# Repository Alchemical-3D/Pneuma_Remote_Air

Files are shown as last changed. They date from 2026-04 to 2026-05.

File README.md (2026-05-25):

<div align="center">

# 🌬️ Pneuma Part Cooling







> [!NOTE]
> **Dual-Pump Architecture**
> Pneuma has recently been upgraded to a dual-pump system (removing the previous direct-acting solenoid valve). This allows for independent, granular control over ambient room air and warm internal chamber air.

A professional, high-performance pneumatic part cooling system designed for the Alchemical-3D ecosystem. Pneuma utilizes vacuum pump(s) and tubes to deliver highly precise, compressed air cooling to toolheads such as the Alembic.

<p align="center">
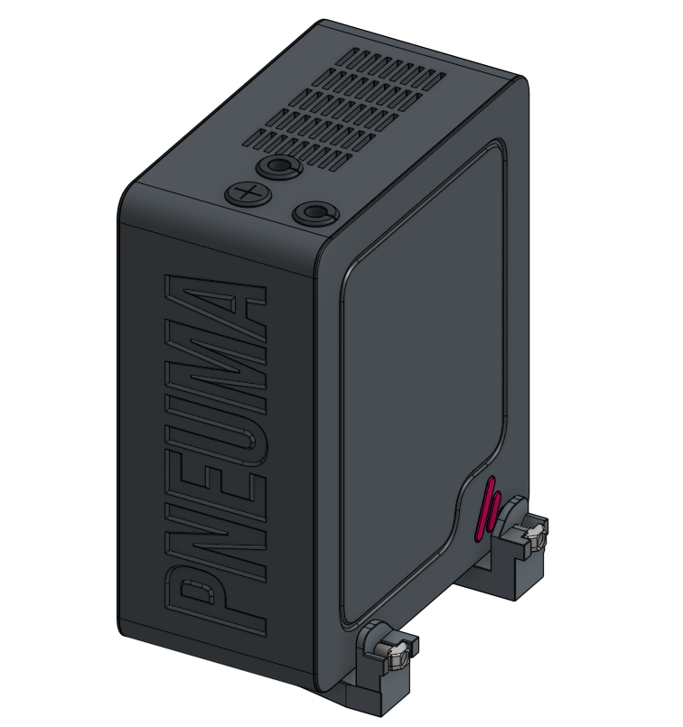
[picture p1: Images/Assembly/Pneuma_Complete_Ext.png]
Pneuma Image 1
  
  &nbsp;
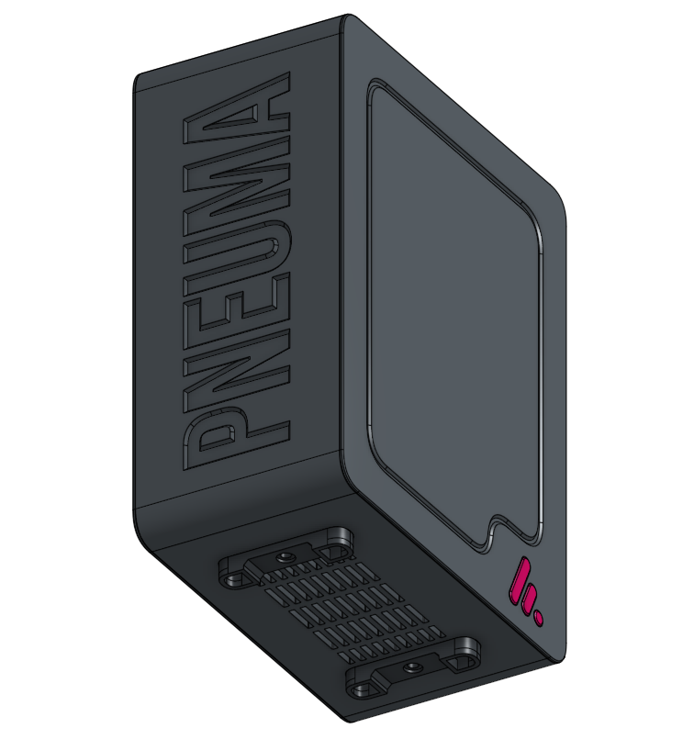
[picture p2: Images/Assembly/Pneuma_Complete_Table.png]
Pneuma Image 2
  
</p>

</div>

<br>

## 📚 Documentation Index

Everything you need to set up and configure the Pneuma system:

| Category | Description |
| :--- | :--- |
| 📋 **[Bill of Materials (BOM)](BOM.md)** | The comprehensive checklist of printed parts, pumps, tubing, and hardware needed. |
| 🛠️ **[Assembly Guide](Assembly_Guide.md)** | A step-by-step mastercloth for putting the Pneuma system together. |
| ⚙️ **[Print Settings](Print_Settings.md)** | Essential slicer configurations, material recommendations, and orientation rules for the enclosures. |

<br>

---
> [!IMPORTANT]
> **Alpha Release**
> This project is currently in the **Alpha phase** of development. Please expect ongoing changes, updates, and improvements to the designs and documentation as the system evolves.

> [!TIP]
> **Looking for a Compatible Toolhead?**<br>
> *If you're interested in this project, check out the **[Alembic Toolhead](https://github.com/Alchemical-3D/Alembic_Toolhead)** project! It is a lightweight, high-performance toolhead designed for the Alchemical-3D ecosystem to utilize Pneuma's remote compressed air architecture.*

## 🌪️ System Capabilities & Benefits

Pneuma provides an alternative approach to part cooling by relocating airflow generation away from the toolhead. By utilizing remote vacuum pumps and pneumatic tubing, Pneuma offers several distinct advantages:

- **Targeted Cooling:** By replacing wide-area blowers with focused, high-velocity air at the nozzle exit, Pneuma and a compatible toolhead will help improve overhangs and fine details.
- **Air Source Control:** When paired with Klipper, users can dynamically select their air source—switching between ambient room air or warm internal chamber air. Pneuma utilizes dual dedicated pumps for this, providing extensive and reliable options for makers to best suit their needs.
- **Smart Macro Integration:** Pneuma uses custom Klipper macros to seamlessly intercept standard part cooling commands (`M106`/`M107`). The system can be commanded manually through the Klipper interface, or entirely through your slicer's standard G-code by embedding a simple mode toggle in your filament profiles.
- **Lightweight Toolheads:** Due to removing the typical 4010 or 5015 blowers, toolheads like the [Alembic](https://github.com/Alchemical-3D/Alembic_Toolhead) shed mass, directly benefiting mechanical properties during operation such as acceleration and jerk.
- **Noise Mitigation:** Pneuma utilizes carefully selected, enclosed pumps (similar to premium aquarium & medical equipment) designed to run quieter than typical "Berd Air" or unshielded pressurized air setups, and when configured properly, can be quieter than the fans themselves.
- **Enhanced Visibility:** Removing bulky fans provides a clearer, less obstructed view of the extrusion process, aiding in visual or camera-based print monitoring.
- **Adaptable Performance:** The modular design allows users to swap pump capacities to better suit their specific cooling needs and materials.

---

## ✨ Key Specifications & Features

- **Cooling Delivery:** High-speed compressed air routed via dedicated pneumatic tubing.
- **Pump Integration:** Low noise, reliable vacuum pump operation.
- **Ecosystem Synergy:** Fully compatible with the Alchemical-3D [Alembic](https://github.com/Alchemical-3D/Alembic_Toolhead) and the A3DP gantry kit, also able to support other berd-air toolheads.
- **Professional Package:** Engineered for repeatability, simple service, and long-term reliability.

---

## 🎛️ Firmware & Control

Pneuma relies on a custom Klipper macro to intelligently route standard part cooling commands to the correct pump. This allows you to retain all native slicer cooling behaviors while utilizing dual air sources.

### Klipper Configuration
The required configuration file can be found here: **[Pneuma_Control.cfg](Firmware/Pneuma_Control.cfg)**

1. **Install:** Place the `Pneuma_Control.cfg` file in your Klipper configuration directory and `[include]` it in your `printer.cfg`.
2. **Assign Pins:** Open the file and assign the correct MCU pins for your Cool Pump and Warm Pump. 
3. **Remove Old Fans:** Ensure you comment out or delete your default `[fan]` component in `printer.cfg` to prevent conflicts.

### How to Use
The system intercepts standard `M106` (fan on) and `M107` (fan off) commands. You can dynamically switch which pump receives these commands using the `SET_PNEUMA_MODE` macro.

**Available Modes:**
- `MODE=COOL` : Routes all cooling commands to the dedicated external cool air pump. Ideal for PLA, PETG, and materials needing maximum thermal extraction.
- `MODE=WARM` : Routes all cooling commands to the internal chamber pump. Ideal for ABS, ASA, and materials sensitive to drafts or warping.
- `MODE=DUAL` : Spins up *both* pumps simultaneously when cooling is requested. Reserved for extreme airflow needs.
- `MODE=OFF` : Completely disables part cooling routing to both pumps, ignoring slicer commands until a new mode is set.

**Implementation Examples:**
- **Via Slicer:** Add `SET_PNEUMA_MODE MODE=WARM` to your filament start G-code for ABS/ASA, or `MODE=COOL` for PLA.
- **Via Console:** Type `SET_PNEUMA_MODE MODE=DUAL` in the Klipper terminal for a quick override.
- **Automatic Routing:** When the slicer requests cooling (e.g., `M106 S255`), Klipper will automatically send the PWM signal only to the active pump(s). If you change modes mid-print, the current fan speed is immediately routed to the new pump!

***

## ⚖️ License

This project is licensed under the **Creative Commons Attribution-NonCommercial-ShareAlike 4.0 International License**. See the [LICENSE.md](LICENSE.md) file for details.

***

**[Join the Discord!](https://discord.gg/aE49DW2xXe)**

> ☕ **Did you find this guide helpful?** 
> 
> My projects are open-source and free for the community. If you've enjoyed my designs and want to support my work, consider [leaving me a tip on Ko-fi](https://ko-fi.com/alchemical3d)! 
>
>

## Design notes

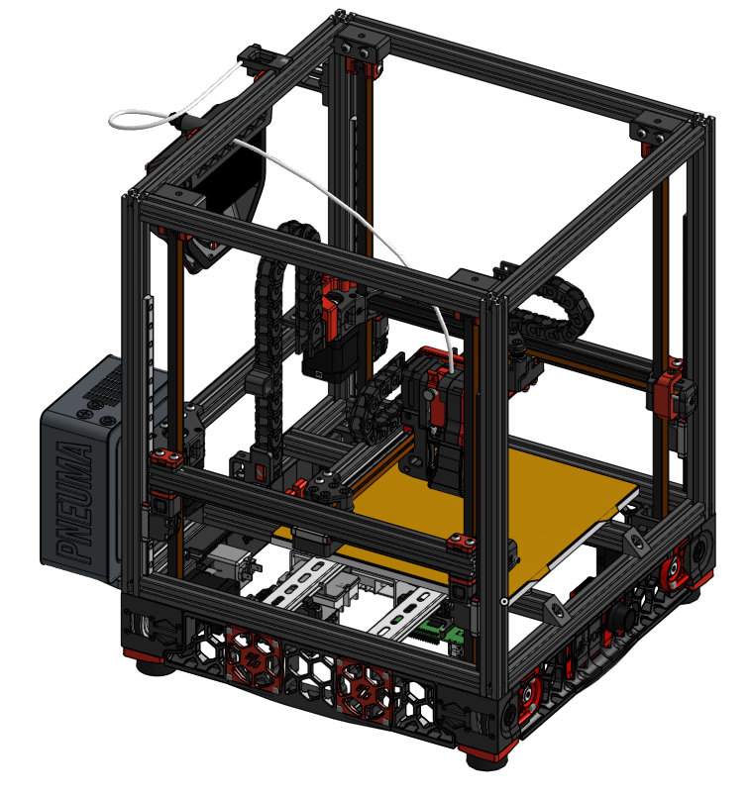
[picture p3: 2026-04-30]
Images/Pneuma_v2-4_side.png

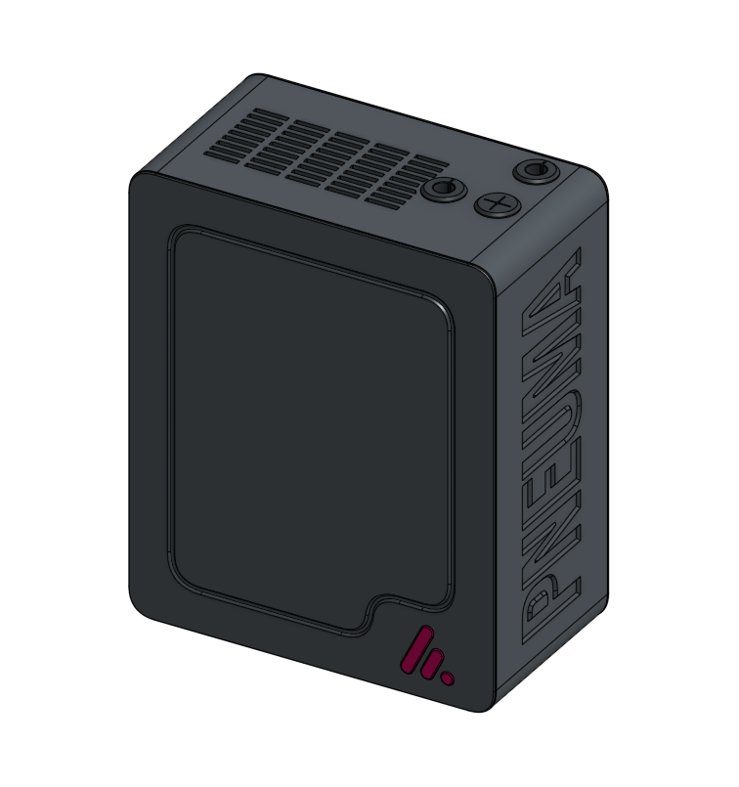
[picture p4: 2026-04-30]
Images/Pneuma.png

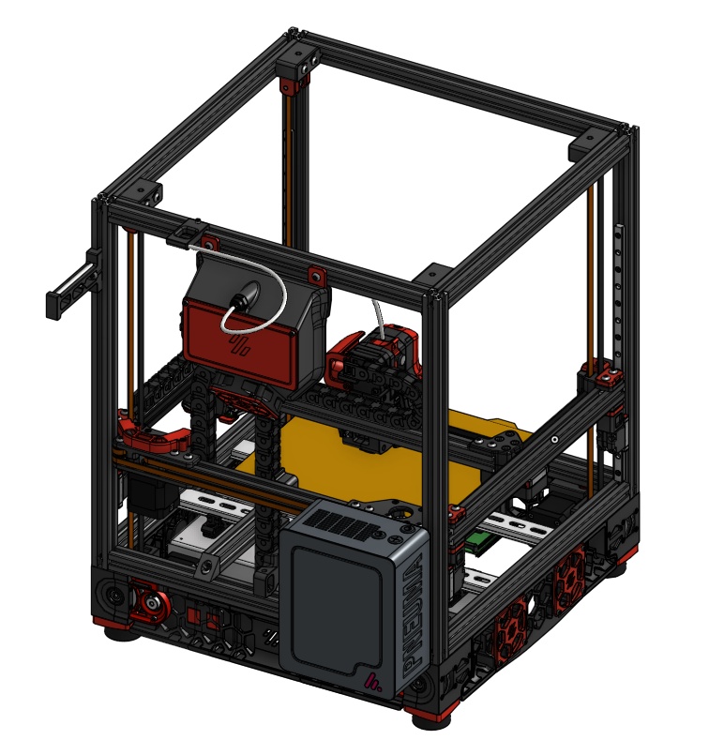
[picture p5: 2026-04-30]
Images/Pneuma_v2-4_back.png

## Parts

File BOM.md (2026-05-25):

# 📋 Bill of Materials (BOM)

This list contains all the 3D-printed and physical hardware required to assemble the Pneuma Part Cooling system.

> [!NOTE]
> **Affiliate Links**
> Alchemical-3D has affiliate status with most of the links below. Purchases using these links helps fund the project at no cost to you!  Some of these links even provide a discount off the retail price.

> [!CAUTION]
> **Valve Selection**
> If you choose to configure your Pneuma with a solenoid valve, it is critical that it is **direct acting** or **vacuum acting**. Pressure-acting valves will not function correctly in this vacuum-based system. Some double solenoid valves are able to fully function as long as the core is shared between solenoids.   Please ask on our [Discord](https://discord.gg/r97kK5B7B7) if you are unsure about a specific valve. 

> [!NOTE]
> **Pump Specifications**
> When selecting a vacuum pump, ensure it meets the following minimum specifications for effective part cooling:
> *   **Flow Rate:** Greater than 10L/min (for part cooling only)
> *   **Pressure:** 70 kPa or better
> *   **Vacuum:** -40 kPa or better
> *   **Voltage:** Ensure the pump's voltage matches your intended power supply configuration. 

## 1. Printed Parts

Print these out using the guidelines specified in the [Print Settings](Print_Settings.md) page.

| Part File Name | Qty | Description / Notes | Material | Color |
| --- | :---: | --- | --- | --- |
| `Main_Body.stl` | 1 | Main Body | ABS/ASA | Primary |
| `Rear_Cover.stl` | 1 | Rear Cover | ABS/ASA | Primary |
| `Front_Cover.stl` | 1 | Front Cover | ABS/ASA | Primary |
| `Logo_Detail.stl` | 2 | Logo Detail | ABS/ASA | Accent |
| `Pump_Mount(s).stl` | 2 | Pump Mount | ABS/ASA | Primary |
| `Tube_Grommet.stl` | 3 | Tube Grommet | TPU | Any |
| `Plug_Grommet.stl` | 3 | Plug Grommet | TPU | Any |
| `Table_Mount.stl` | 2 | Optional Table Mount | TPU | Any |
| `Extrusion_Mount_A.stl` | 1 | Optional Extrusion Mount A | ABS/ASA | Primary |
| `Extrusion_Mount_B.stl` | 1 | Optional Extrusion Mount B | ABS/ASA | Primary |
| `Tube_Fitting.stl` | 3 | Fitting, Hardware Dependent | TPU | Any |

> [!NOTE]
> **Additional Printed Parts**
> Additional printed parts may be required for specific use cases, such as tube adaptors for vacuum pumps that have different outlet sizes than the standard pneumatic tubing. A folder will eventually be added to the repository containing a selection of these adaptors for the most common sizes (e.g. 6mm, 8mm, etc.).

## 2. Fasteners and Hardware

| Item | Qty (Est.) | Description |
| --- | :---: | --- |
| **[M3x5x4 Heatsets](https://kb-3d.com/store/inserts-fasteners-adhesives/278-brass-heat-set-threaded-insert-for-plastic-m3x5x4mm.html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)** | 5 | Used in the Rear Cover for the Pump Mount |
| **[M3x10 SHCS](https://amzn.to/3P57ILQ)** | 2 | Foot Mounting (Extrusion or Table) |
| **[M3x8 SHCS](https://amzn.to/3P57ILQ)** | 2 | Pump Mounting |
| **[Pneumatic Tubing](https://amzn.to/3P3YzDd)** | 1 | Other diameters will require changes to BOM |
| **[Pneumatic Fitting (1/8 NPT, 6mm OD)](https://amzn.to/3P3YzDd)** | 1 | Valve Chamber Inlet  |
| **[Pneumatic Fitting Right Angle(1/8 NPT, 6mm OD)](https://amzn.to/3P3YzDd)** | 1 | Pump Intake: Helps with tubing bend radius |
| **[M5x12 BHSC](https://amzn.to/42p7gvb)** | 2 | Extrusion Mounting |
| **[M5 Roll in T Nut](https://kb-3d.com/store/extrusion-framing/252-t-nut-drop-inroll-in-20-series-6mm-slot-width-m5-threads-1657989339400.html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)** | 2 | Extrusion Mounting |

## 3. Electronics

| Item | Qty | Description |
| --- | :---: | --- |
| **[Vacuum Pump(s)](https://amzn.to/4ubXFnG)** | 1 or 2 | This link is for the version of the pump that is currently installed in the alpha.  |
| **[Solenoid Valve 3-Way Vacuum Direct Acting](https://amzn.to/3Qx0UXL)** | 1 | Optional, required for air temperature control. |
| **[20AWG High-Temp FEP Wire](https://kb-3d.com/store/wiring-connectors/5530-9177-3do-high-temperature-motion-rated-tc-fep-wire-multiple-sizes-colors.html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)** | As Needed | 20AWG, depends on pump current requirements, link is excellent option. |
| **[5-PIN Single Row Molex Micro-Fit 3.0](https://amzn.to/3ODzcbj)** | 1 Each | Male/Female Connectors, pins not included |

> [!IMPORTANT]
> **Part Flexibility & Modifications**
> There is flexibility in the hardware and components you can use for this build. However, please note that veering from the listed parts may require you to modify the 3D models to accommodate your specific hardware. To make this process easier, **STEP files are provided** in the GitHub repository for all printed parts. If you need help with modifications or have specific hardware requests, feel free to join our [Discord](https://discord.gg/r97kK5B7B7) and reach out!

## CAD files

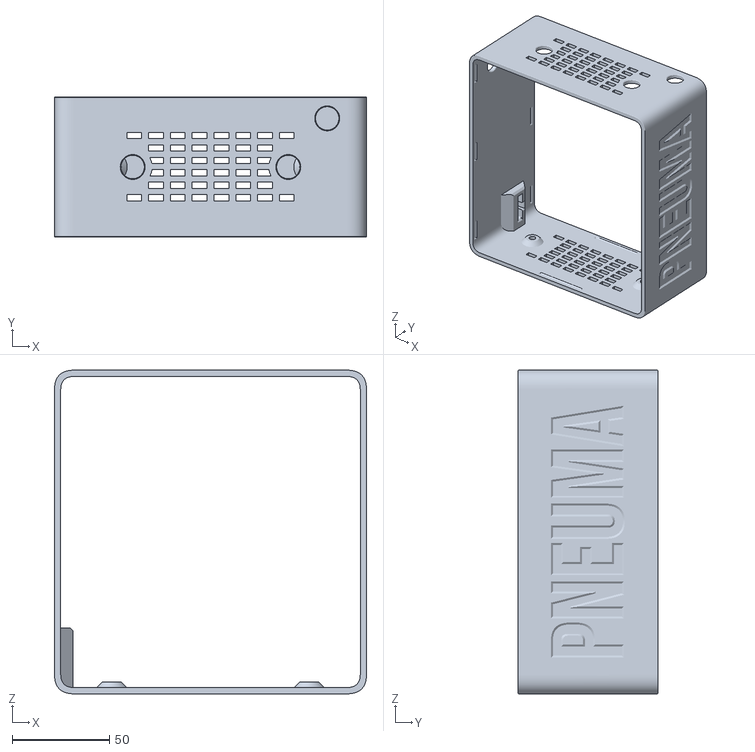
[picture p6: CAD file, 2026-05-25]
STL_Files/Pneuma_201 parts - Main_Body.stl
160.4 x 72.0 x 166.4

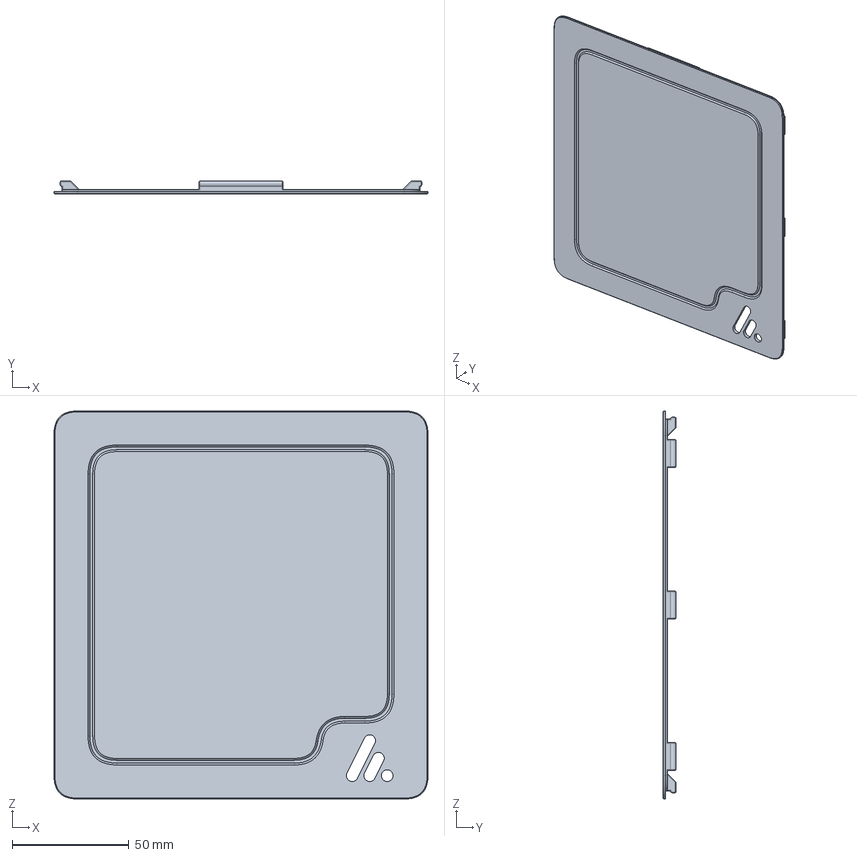
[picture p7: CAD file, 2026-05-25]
STEP_Files/Pneuma_201 parts - Front_Cover(1).step
160.4 x 5.60 x 166.4 mm

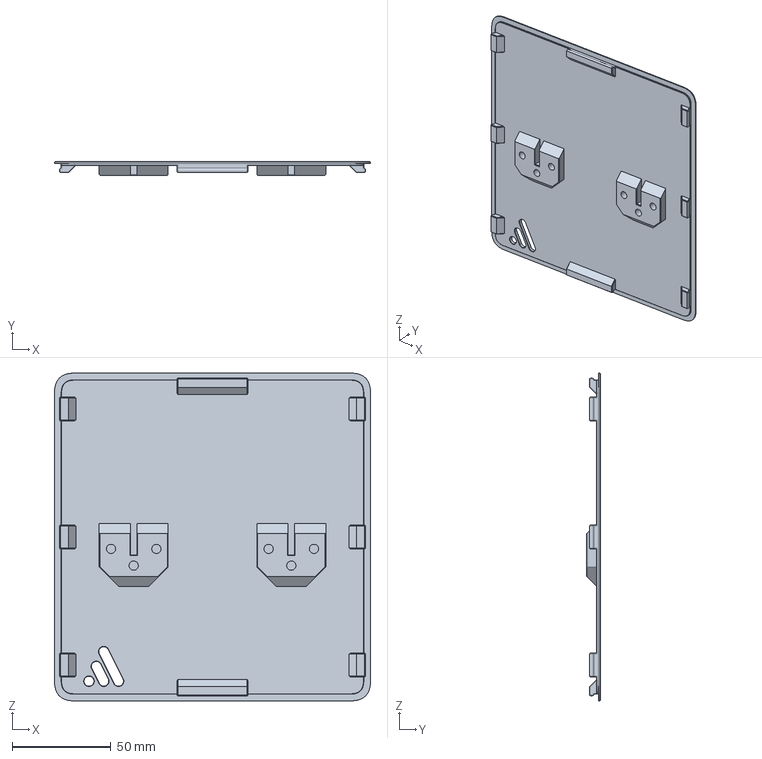
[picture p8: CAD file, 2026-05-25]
STEP_Files/Pneuma_201 parts - Rear_Cover(1).step
160.4 x 7.00 x 166.4 mm

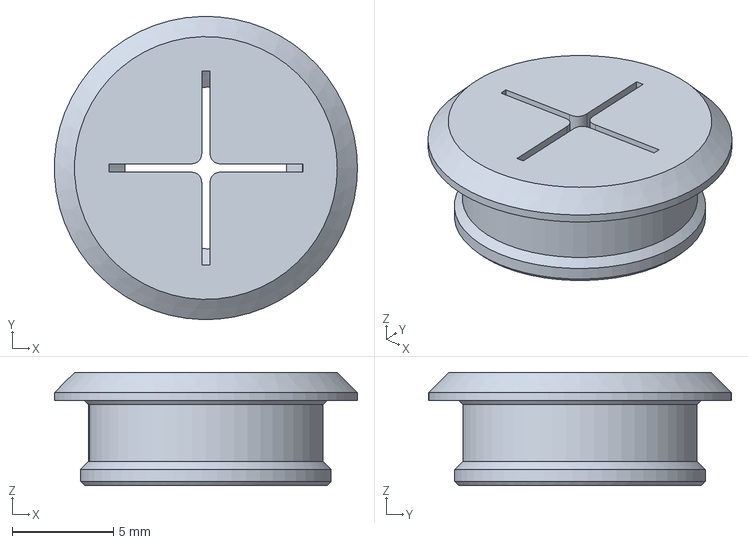
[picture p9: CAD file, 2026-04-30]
STEP_Files/Pneuma_201 - Plug_Grommet_TPU.step
15.0 x 15.0 x 5.60 mm

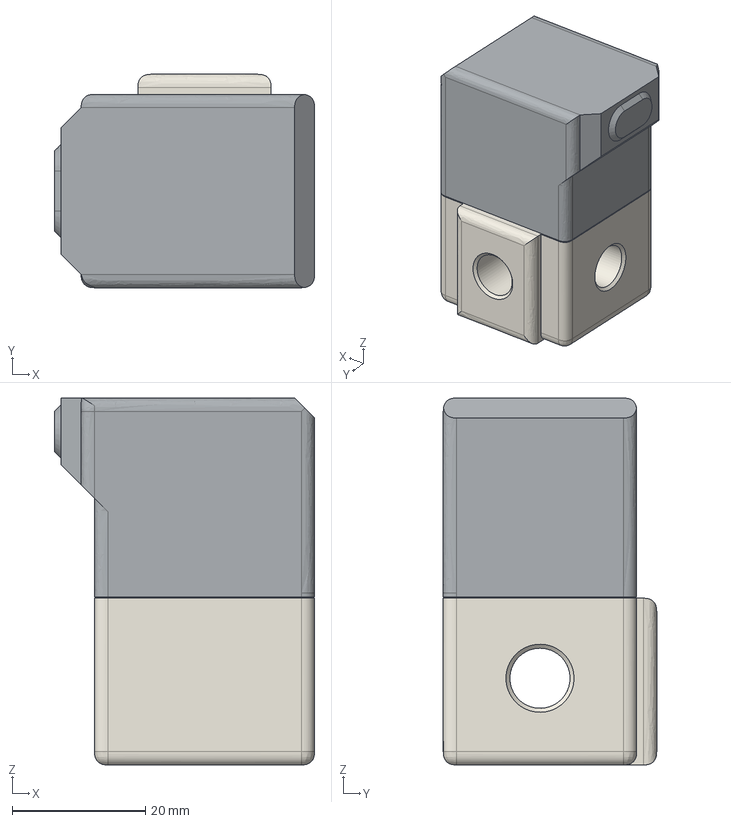
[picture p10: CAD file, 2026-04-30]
STEP_Files/Pneuma_201 - 1-8-NPT Direct_Action_Valve.step
39.0 x 32.0 x 55.0 mm

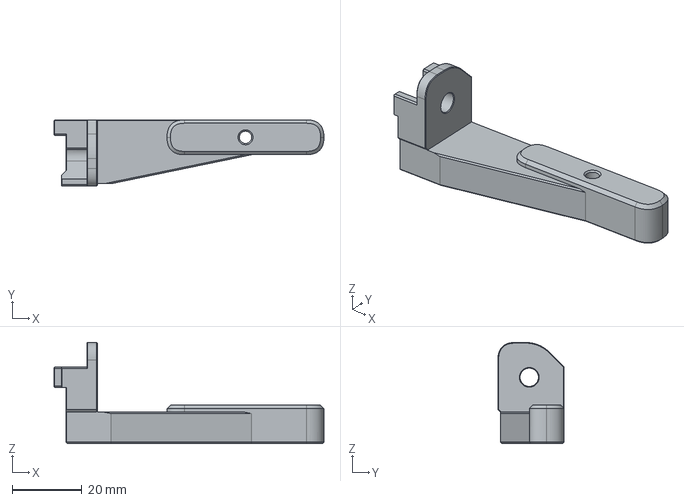
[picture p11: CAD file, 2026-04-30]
STEP_Files/Pneuma_201 - Extrusion_Mount_B.step
77.4 x 19.0 x 29.0 mm

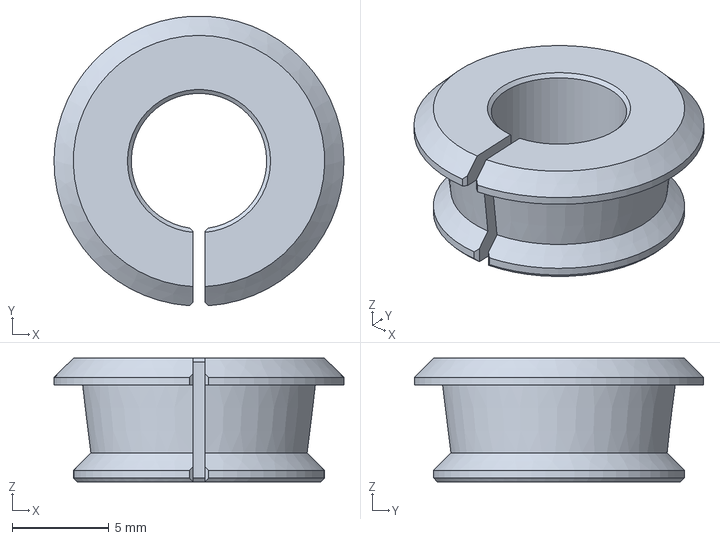
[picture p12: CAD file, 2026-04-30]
STEP_Files/Pneuma_201 - TPU_Grommet.step
15.0 x 15.0 x 6.40 mm

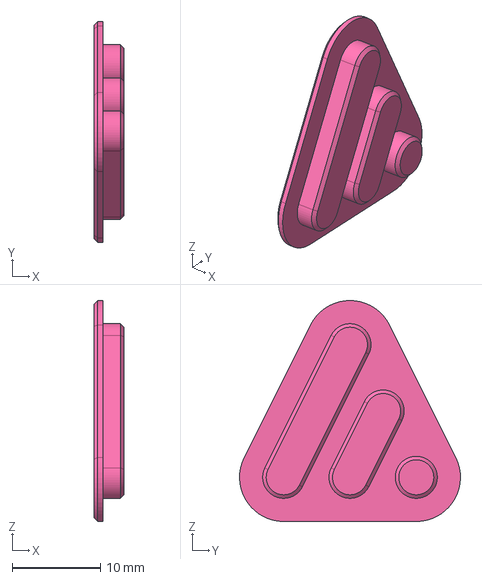
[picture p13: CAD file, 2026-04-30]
STEP_Files/Pneuma_201 - Logo_Detail.step
3.40 x 25.0 x 25.0 mm

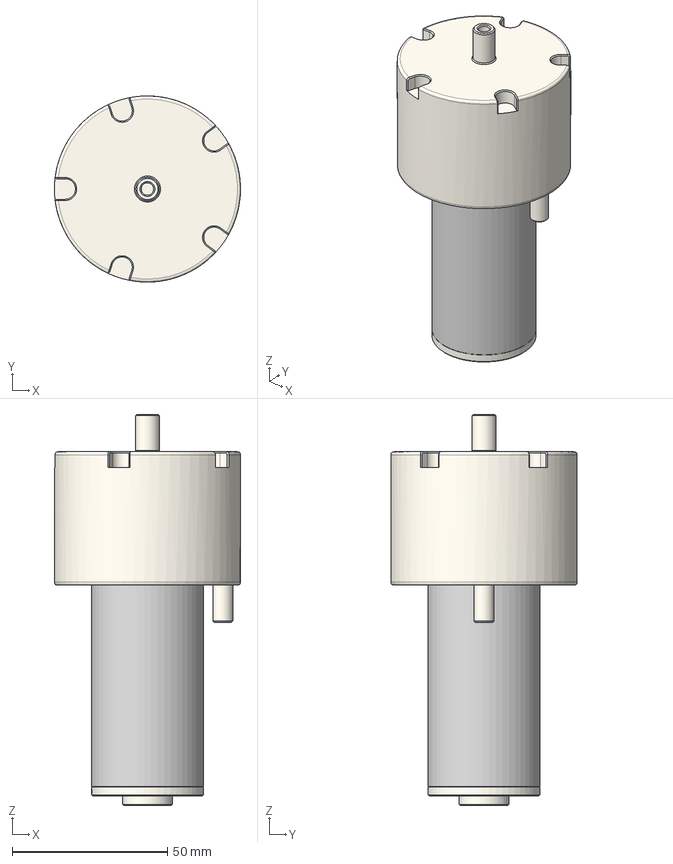
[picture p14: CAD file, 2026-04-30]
STEP_Files/Pneuma_201 - Vacuum_Pump.step
60.0 x 60.0 x 126.0 mm

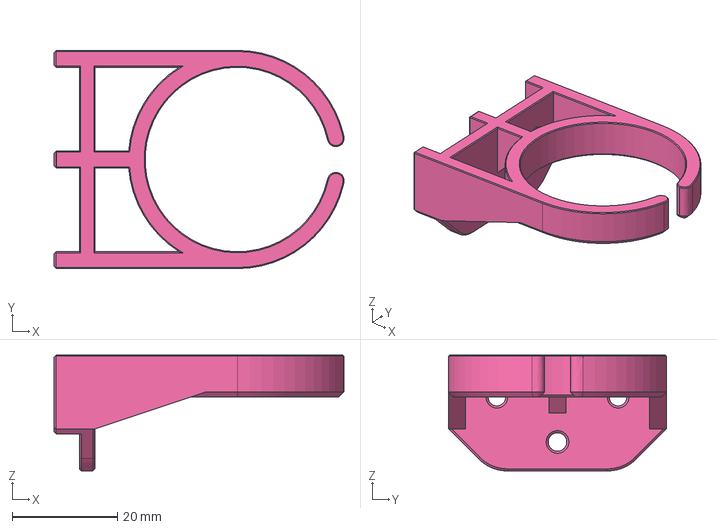
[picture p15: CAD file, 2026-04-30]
STEP_Files/Pneuma_201 - Pump_Mount.step
55.0 x 41.4 x 22.0 mm

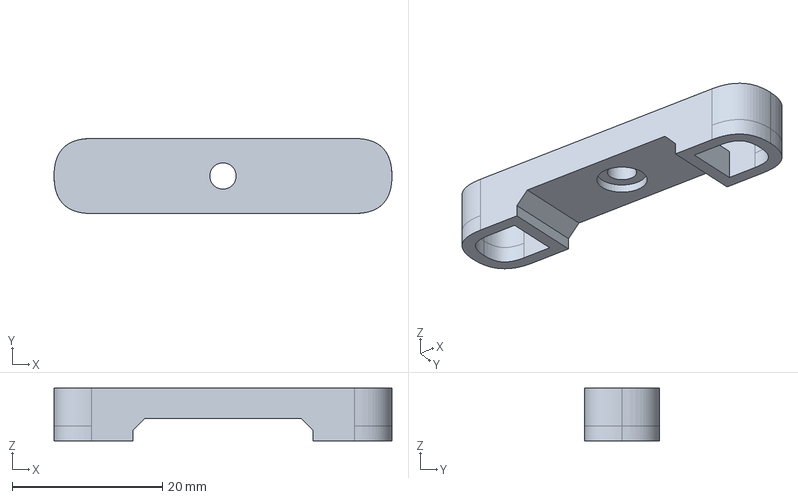
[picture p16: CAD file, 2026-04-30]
STEP_Files/Pneuma_201 - Table_Mount_TPU.step
45.0 x 10.00 x 7.00 mm

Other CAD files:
STEP_Files/Pneuma_201 parts - Main_Body(1).step
STL_Files/Pneuma_201 parts - Front_Cover.stl
STL_Files/Pneuma_201 parts - Rear_Cover.stl
STEP_Files/Pneuma_201 - Extrusion_Mount_A.step
STL_Files/Pneuma_201 - Extrusion_Mount_A.stl
STL_Files/Pneuma_201 - Extrusion_Mount_B.stl
STL_Files/Pneuma_201 - Logo_Detail.stl
STL_Files/Pneuma_201 - Plug_Grommet_TPU.stl
STL_Files/Pneuma_201 - Pump_Mount.stl
STL_Files/Pneuma_201 - TPU_Grommet.stl
STL_Files/Pneuma_201 - Table_Mount_TPU.stl
STL_Files/Pneuma_201 - Vacuum_Pump.stl

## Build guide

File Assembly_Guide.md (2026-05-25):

# 🛠️ Assembly Guide

Welcome to the assembly guide for the Pneuma Part Cooling system.

> [!NOTE]
> **Dual-Pump Architecture**
>
> Pneuma has recently been upgraded to a dual-pump system (removing the previous direct-acting solenoid valve). This allows for independent, granular control over ambient room air and warm internal chamber air.  It also means this assembly guide has changed, but the core principals remain.  This will be updated at a later date.

## Tools Required
- Hex keys
- Flush cutters
- Tube cutter
- Soldering iron (for heat set inserts)

### Note
> [!WARNING]
> **Builder Responsibility**
>
> This is an aftermarket engineering project. You are solely responsible for your own safety and the integrity of your equipment when building and operating this system. By utilizing these files and instructions, you accept all liability.

---

## Step 1: Heat Set Inserts

Begin by installing the M3 heat set inserts into the printed parts. Ensure they are flush with the surface to allow for proper mating of the components.

<div align="center">
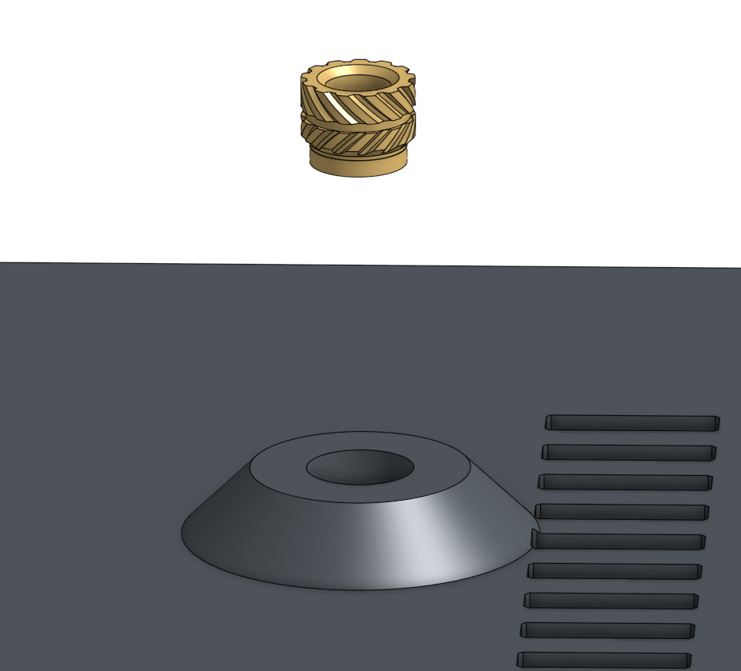
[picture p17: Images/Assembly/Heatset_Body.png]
Heat Set Body
  
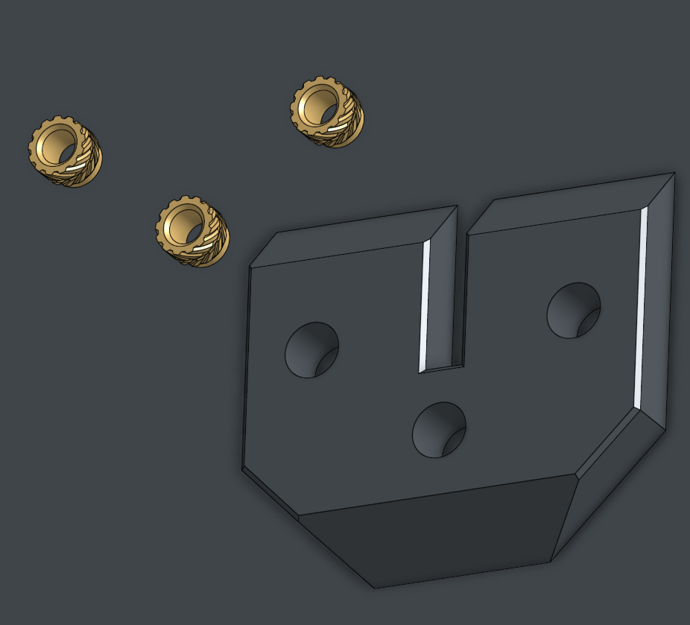
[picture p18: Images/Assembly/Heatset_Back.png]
Heat Set Back
  
</div>
<br>
*Fig. 1: Install M3 inserts into the Main Body and Rear Cover.*

---

## Step 2: Pump Mounting

Attach the vacuum pump to the pump mount using the appropriate screws. Ensure the pump is seated securely.

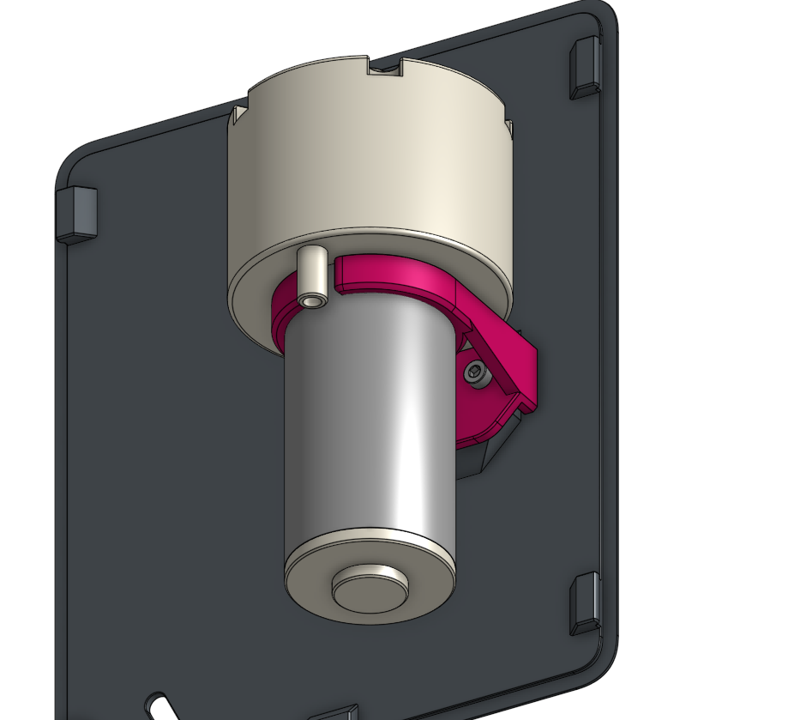
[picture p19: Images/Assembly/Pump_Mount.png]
Pump Mount

<br>
*Fig. 2: Secure the pump to the Pump Mount.*

---

## Step 3: Main Assembly

Bring together the main components. Route the pneumatic tubing and any necessary wiring through the designated channels before closing the covers.

> [!NOTE]
> **Threaded Fittings**
>
> Teflon tape is recommended at a minimum on the pressure side of the line when using threaded fittings.

> [!NOTE]
> **Solenoid Valve Routing**
>
> Typical direct action solenoid valves will have a common outlet, and two switching outlets. The common outlet must go to the pump intake, and for ABS/ASA and higher tier filament machines, it is recommended to have at least one line draw from the chamber to ensure warmer air is an option to avoid warping.

> [!WARNING]
> **Tubing Bend Radius**
>
> Take care when routing the pneumatic tubing. Avoid sharp bends and do not exceed the minimum bend radius of your tubing. Kinked lines will severely restrict airflow and reduce cooling system performance.

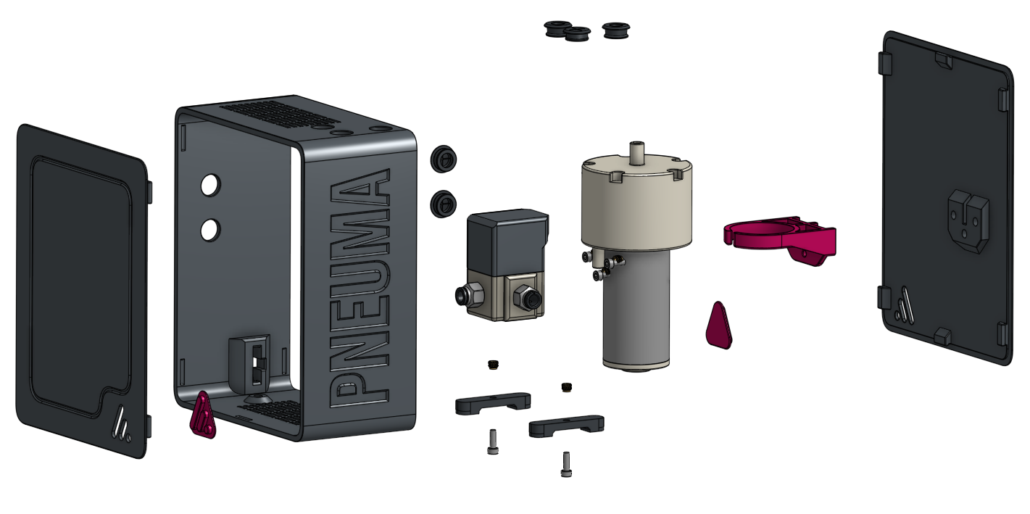
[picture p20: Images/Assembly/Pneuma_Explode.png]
Pneuma Exploded View

<br>
*Fig. 3: Exploded view of the primary Pneuma assembly.*

---

## Step 4: Optional Mounting Solutions

Depending on your setup, you can mount the Pneuma system either to the printer's aluminum extrusion or directly to a table/enclosure surface. 

<div align="center">
  Extrusion Mount
  Table Mount
</div>
<br>
*Fig. 4: Optional Extrusion mount (left) and Table mount (right).*

---

### End of Assembly
The Pneuma Part Cooling system is now assembled and ready for integration!

***

> ☕ **Did you find this guide helpful?** 
> 
> My projects are open-source and free for the community. If you've enjoyed my designs and want to support my work, consider [leaving me a tip on Ko-fi](https://ko-fi.com/alchemical3d)! 
>
>

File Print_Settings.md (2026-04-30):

# ⚙️ Print Settings

*This document is currently a placeholder for the Pneuma Part Cooling system Print Settings.*

## Recommended Materials
- **Pump Enclosure:** ASA / ABS (for thermal resistance) or PETG.
- **Mounts:** ASA / ABS.

## General Slicer Settings
- **Layer Height:** 0.2mm
- **Infill:** 40% Grid or Gyroid
- **Wall Loops:** 4
- **Top/Bottom Layers:** 5

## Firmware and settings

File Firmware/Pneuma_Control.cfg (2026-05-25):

# Pneuma Dual-Pump Control System
# This configuration replaces the standard [fan] with two [fan_generic] definitions
# and overrides the M106/M107 commands to route air based on the selected mode.

# ==============================================================================
# 1. HARDWARE DEFINITIONS
# ==============================================================================
# Define the pins for your two pumps here. 
# IMPORTANT: You must comment out or remove any existing [fan] sections in your main printer.cfg

[fan_generic pump_cool]
pin: PF7 # <--- UPDATE THIS TO YOUR COOL PUMP PIN
min_power: 0.15
max_power: 1.0
#kick_start_time: 0.5
shutdown_speed: 1

[fan_generic pump_warm]
pin: PF9 # <--- UPDATE THIS TO YOUR WARM PUMP PIN
min_power: 0.15
max_power: 1.0
#kick_start_time: 0.5
shutdown_speed: 1

# ==============================================================================
# 2. STATE MANAGEMENT
# ==============================================================================
[gcode_macro PNEUMA_STATE]
description: Stores the current state of the Pneuma system
variable_mode: "COOL" # Default mode on startup (Options: COOL, WARM, DUAL, OFF)
variable_last_speed: 0.0 # Stores the last requested speed to re-apply when switching modes
gcode:
    # This macro just holds variables for the other macros to use.
    # Do not call this directly.

# ==============================================================================
# 3. MODE SWITCHING MACRO
# ==============================================================================
[gcode_macro SET_PNEUMA_MODE]
description: Set the active Pneuma pump mode (COOL, WARM, DUAL, OFF)
gcode:
    {% set new_mode = params.MODE|default("COOL")|string|upper %}
    {% set valid_modes = ["COOL", "WARM", "DUAL", "OFF"] %}
    
    {% if new_mode in valid_modes %}
        SET_GCODE_VARIABLE MACRO=PNEUMA_STATE VARIABLE=mode VALUE='"{new_mode}"'
        {action_respond_info("Pneuma Pump Mode set to: %s" % new_mode)}
        
        # Automatically re-apply the last known fan speed to the new mode
        {% set last_speed = printer["gcode_macro PNEUMA_STATE"].last_speed %}
        {% if last_speed > 0 %}
            # If the fan was on, turning it "on" again will re-route the air
            M106 S{ (last_speed * 255)|int }
        {% else %}
            # Ensure both pumps are off if the last speed was 0
            M107
        {% endif %}
    {% else %}
        {action_respond_info("ERROR: Invalid Pneuma mode '%s'. Must be COOL, WARM, DUAL, or OFF." % new_mode)}
    {% endif %}

# ==============================================================================
# 4. SLICER COMMAND OVERRIDES (M106 / M107)
# ==============================================================================
[gcode_macro M106]
description: Override standard part cooling command to route to active Pneuma pump
gcode:
    # Get requested speed, default to 100% (255) if S parameter is missing
    {% set raw_speed = params.S|default(255)|float %}
    
    # Convert 0-255 range to 0.0-1.0 percentage
    {% set safe_speed = raw_speed / 255.0 %}
    {% if safe_speed > 1.0 %}
        {% set safe_speed = 1.0 %}
    {% elif safe_speed < 0.0 %}
        {% set safe_speed = 0.0 %}
    {% endif %}
    
    # Store this speed so we can recall it if the user switches modes mid-print
    SET_GCODE_VARIABLE MACRO=PNEUMA_STATE VARIABLE=last_speed VALUE={safe_speed}
    
    # Get the current mode
    {% set mode = printer["gcode_macro PNEUMA_STATE"].mode %}
    
    # Apply speeds based on the mode
    {% if mode == "COOL" %}
        SET_FAN_SPEED FAN=pump_cool SPEED={safe_speed}
        SET_FAN_SPEED FAN=pump_warm SPEED=0.0
    {% elif mode == "WARM" %}
        SET_FAN_SPEED FAN=pump_cool SPEED=0.0
        SET_FAN_SPEED FAN=pump_warm SPEED={safe_speed}
    {% elif mode == "DUAL" %}
        SET_FAN_SPEED FAN=pump_cool SPEED={safe_speed}
        SET_FAN_SPEED FAN=pump_warm SPEED={safe_speed}
    {% elif mode == "OFF" %}
        SET_FAN_SPEED FAN=pump_cool SPEED=0.0
        SET_FAN_SPEED FAN=pump_warm SPEED=0.0
    {% endif %}

[gcode_macro M107]
description: Override standard part cooling off command
gcode:
    # Store that the speed is now 0
    SET_GCODE_VARIABLE MACRO=PNEUMA_STATE VARIABLE=last_speed VALUE=0.0
    
    # Turn off both pumps
    SET_FAN_SPEED FAN=pump_cool SPEED=0.0
    SET_FAN_SPEED FAN=pump_warm SPEED=0.0

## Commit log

2026-04-30 Replace placeholder images with assembly images
    Updated images in README to reflect assembly images.
2026-04-30 Change CRITICAL note to CAUTION in BOM.md
2026-04-30 Replace placeholder images with assembly images
    Updated images in README to reflect assembly completion.
2026-04-30 Update README with information about Alembic Toolhead
    Added a tip about the Alembic Toolhead project to the README.
2026-04-30 Update Alembic Toolhead link in README
2026-05-14 Update Vacuum Pump link in BOM.md
2026-05-24 Adjust quantity for Vacuum Pump(s) in BOM
    Updated quantity for Vacuum Pump(s) from 1 to 1 or 2.
2026-05-25 Revise README for Pneuma system updates
    Updated the README to reflect changes in the Pneuma system, including the removal of the direct-acting valve and the introduction of a dual-pump architecture for improved air source control.
2026-05-25 Update Pump Mount quantity in BOM
2026-05-25 Revise assembly guide for dual-pump system
    Updated assembly guide to reflect dual-pump architecture changes.
2026-05-25 Enhance README with Klipper setup and modes
    Updated documentation to include Klipper configuration and usage instructions.

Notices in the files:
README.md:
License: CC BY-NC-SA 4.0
